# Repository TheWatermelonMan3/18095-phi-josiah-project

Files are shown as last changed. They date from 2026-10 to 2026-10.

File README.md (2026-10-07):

Review Assignment Due Date (https://classroom.github.com/a/fbvAo0RR)
# Clank
Team Member(s): Phi Nguyen, Josiah Main

- Write up a paragraph or two that describes your final hack's objective, and all its sensors and actuators.

TODO: Clank is designed to autonomously detect soda cans using a camera and computer vision model, navigate toward the detected can using two stepper-motor–driven wheels, and then “collect” it using a forklift mechanism controlled by an ultrasonic-sensor trigger, a stepper motor for lifting, and a servo for locking the can in place.

# Schematics and Block Diagrams

Here is the block diagram.

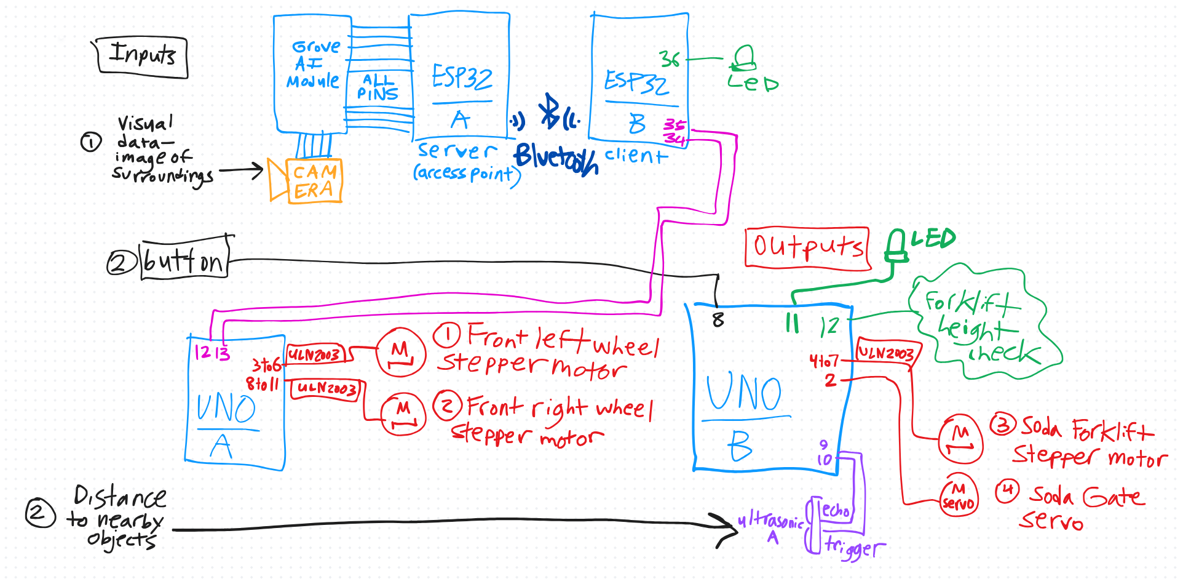
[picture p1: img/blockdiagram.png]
Block Diagram


Here is the schematic.

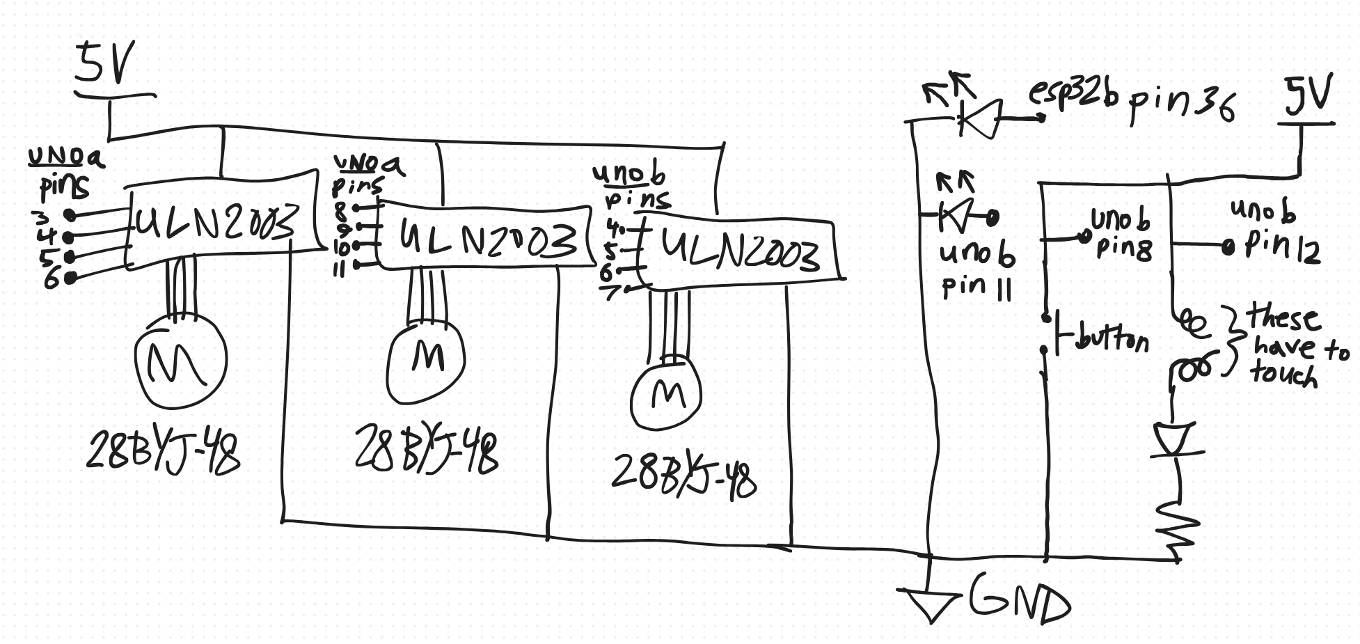
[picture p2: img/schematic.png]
Schematic


# Materials

| Item | Source (URL) |
| --- | --- |
| Grove AI Vision v2  | https://wiki.seeedstudio.com/grove_vision_ai_v2/ |
| ESP32 WROOM | https://www.alibaba.com/pla/ESP32-WiFi-BLE-ESP32-WROOM-32U-IOT-Development_1601041257369.html?product_id=1601041257369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 |
| 3x Stepper Motor | https://www.aliexpress.us/item/3256806043512709.html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 |
| Servo | https://www.aliexpress.us/item/3256807034882140.html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 |
| Ultrasonic Sensor | https://www.alibaba.com/pla/HC-SR04-Ultrasonic-Distance-Measurement-Module-HC-SR04SR04PSR04Ultrasonic_1601247237258.html?product_id=1601247237258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 |

Additionally, please upload any design files for laser-cut or 3D-printed pieces to the parts directory.

# Narrative

- Describe the process of building your final hack project.
- Did the design change as you worked on it?
- Include any problems you encountered, and how you addressed them. 
- This section should be at least ~500 words. Be reflective!

There were two separate but major goals for Clank. The first was getting the computer vision working, and the second was designing the chassis.

### Computer Vision

On the computer vision side, there was an issue getting the Grove module to work through the Seeed Studio website. Seeed Studio provides a UI that lets you upload computer vision models to their Grove AI modules very easily. I had followed the documentation correctly. I soldered the pins to the ESP32, connected the ESP32 to the Grove AI module, connected the Arduino camera with the blue strip facing up (as shown in the documentation), plugged the Grove AI module into my laptop via USB-C, and followed the instructions for uploading a model. However, after the model uploaded, the module would reset every time I tried to invoke the preview.

After what felt like hundreds of resets and boots, I started to think the module was just broken. I searched online—“Grove AI invoke not working”—and scrolled through different forums. People mentioned specific OS requirements, browser versions, etc. It wasn’t until I stumbled upon a very specific message telling someone to try flipping the camera: instead of the blue strip facing up, flip it so the blue strip faces down. I was hesitant because the documentation explicitly shows it facing up, but I didn’t have any other solutions, so I tried it. And—what do you know—it worked. I was pretty mad at the documentation. They need to fix that.

Anyway, with the Grove AI module finally able to invoke the preview, I could test different computer vision models, and we found one that fit our soda-can-identifying needs. After reading the documentation for getting the Grove module working through the Arduino IDE and implementing the code, I was able to get inference results printing in the Serial Monitor. That meant that when the model detected a soda can, its X-coordinate would be printed. This was a huge win.

The second step was turning predictions into movement. Since all the pins on the ESP32 were being used by the Grove AI module, we needed a second ESP32—with free pins—to communicate with the ESP32 on the Grove module. This was our first time setting up wireless communication between two ESP32s, so it came with a lot of challenges. The ESP32 on the Grove AI module is called the XIAO, and it does not follow the standard Bluetooth protocol used in traditional ESP32s, so we had to follow the Seeed Studio documentation for it. I was already suspicious of the documentation, but some forums had sample code, so we started with that.

The next big problem was that after we got the ESP32s talking wirelessly, it only worked when both were connected to my laptop. The moment I detached one and powered it with its own battery, it stopped working. After two days of debugging, nothing worked. I read online that a 9V battery might not provide consistent power, but I didn’t think it was a big deal because I thought the output was capped at 5V anyways. After taking the ESP32s to class and getting the TAs to help—with no success—then Tom came, looked at it for 2.6 seconds, and suggested that the battery might be low. I took out my multimeter, measured the voltage across the terminals, and found that my 9V battery was actually sitting at 6V.

After switching the battery out, the ESP32s worked completely wirelessly and independent of my laptop. The second ESP32—with free pins—was able to light up an LED when the XIAO detected a soda can.

### Robot Structure

Making the robot frame and parts was a challenge in itself. This was our first non-trivial 3D modeling and 3D printing experience. We had to learn a lot about Onshape CAD software, for example how to make construction geometries and how to assemble and mate parts to simulate how the parts would fit together. Then we also had to learn a lot about 3D slicing and printing software. Here is a summary of my challenges.

For a few days we were making the model of the wheels. We found the measurements of the 28BYJ-4 5-volt stepper motor and added a slot/hole the correct size to stick the wheel directly onto the rotating part of the motor. We didn't end up using this model - more on this later. We had to make it cleverly so that it could be printed from the bottom up with no support material. This was a challenge for designing all the models because when we think about a 3D object we usually don't have such restrictions in mind, so we might make a bridge or ceiling over something. Of course, this would be impossible to print. This went on to become a recurring theme in the modeling process.

Then we made the forklift part which would hold the soda can. We found the measurements of a standard 355mL soda can online and made a forklift with a circular rim of the same size. We added a chamfer to slope it down to the floor allowing the can to slip in smoothly. However we also needed to have a rack on the back of it so that it could be moved up and down by a pinion gear. This would be impossible to print in one piece with the forklift itself, so we cut a slot into the model and built the pinion separately so it could slide in.

Building the rack itself was also a challenge. We used an Onshape script to generate the pinion gear, and then cut a hole in it according to the measurement of the 28BYJ-4 stepper motor. The hard part was when we had to contruct the pinion ourselves with the proper angles. This was difficult due to our limited Onshape knowledge. In particular we had to learn how to make construction lines, and we weren't sure how to generate lines with a certain angle fixed between them. But the rack and pinion ended up meshing satisfactorily, which was a huge win!
We used this video to learn how to make the rack: https://www.youtube.com/watch?v=wLZq1ZXhPfE

Then we wanted to test the rack and pinion so we had to make a mate relation allowing them to move with one another. This was a steep learning curve because w didn't even know what a mate relation was. After about a day of work, we connected the rack and pinion in simulation, and the forklift was looking like it would move nicely.

We continued modeling more parts, including a chassis. The chassis had a wide rail to support the forklift while it slid up and down. We opted for having skids on the back rather than four wheels - which may have been suboptimal because dragging on the ground led to a lot of friction. We realized in the chassis we had another item we couldn't simply print from the bottom up - a place for the stepper motor to connect. We modeled a stepper motor holder piece and made three copies of it. We modeled a ceiling and a piece to slot into it which would hold the camera with four pins. Finally the models were finished and it was time to print!

We went to TechSpark to print and found that the models were too large to be contained in the Ender Creality 3 printers we were using. We redesigned many parts to slightly trim down the size. We attempted to print the parts on two printers, but on the first attempt both prints failed. We worked with TechSpark staff to identify that this was a leveling issue with the build plate. We leveled the printers properly and printed them over the weekend leading up to the final showcase. One print failed due to extruding problems, but we got the chassis, a stepper holder, skids, forklift, rack, pinion, and many other items. This was great! Some of them had tolerances a bit off and needed to be sanded down and filed to fit, particularly the skids and the forklift.

We realized the roof would take too many hours to print, but it was essentially a flat rectangular prism with holes in it. This made it easy to laser cut. We converted one of our Onshape 3D models to a .dxf file and ran it through the Epilog laser cutter. It cut perfectly on the first try and fit right on top of the chassis. We hot glued the roof to the chassis so it wouldn't slide around.

We finally got them all fitting properly, while we worked on printing the other parts that had failed to print. From this we got some wheels, stepper holders, and a camera holder. Unfortunately none of these ended up being usable - the wheels had holes too large to fit on the pegs of the stepper motors; the stepper holders were too thick, not allowing clearance for the wheels to fit onto the pegs of the stepper motors; the camera holder didn't print properly and the pins on it snapped.

We printed new, thinner, stepper holders in white, which worked great. Along with them we printed a sturdier camera mount, including having a draft angle on the pins of the camera holder so they tapered. Being thicker at the base, the pins were less likely to snap off. Now we just needed the wheels.

Making the wheels ended up being one of the most stressful parts of the process. After two failed prints that didn't work because of sloppy CAD design, we realized it was wasting lots of time and lots of filament to 3D print each time. We tried to cut wheels out of acrylic. On our first try the holes in the wheels were misaligned because we cut the wheel out of the acrylic sheet before cutting the hole into it, so the wheel fell down and moved during cutting. On my second try, the holes were aligned alright, but sadly the holes were a little too loose, making them wiggle on the stepper motors. Worse, they were slick acrylic and couldn't get enough traction to roll the robot forward. Wanting to move on to assembling the robot and coding, we opted to just add some hot glue around the wheel rims and axle holes to make the holes smaller and add traction to the rims.

In order to put the parts together we used black electrical tape. Some of the parts moved around slightly when the tape was not tight enough, but it got the job done. Finally the robot frame was completely built, just in time to put the electronics on and write the code for the final showcase!

### Motor and Power Issues

When we had added the stepper motors, we had a lot of issues powering them. The first issue was that we powered them from the Arduino Uno boards. This is not allowed because the motor driver draws far too much current to feasibly come from the Uno. So then we tried to shift to another battery supply. Eventually we connected 3 9V batteries with 5V voltage regulators in parallel on a breadboard. This allowed us to supply 3 times the current at the same voltage. Even then, the motors were not getting a lot of current, making them very, very slow. This was an issue we faced even going into the final showcase. There was also the possibility that we might have damaged certain of the components like the Uno board by attempting to run them at higher speed and lower power than was reasonable. We found that the Uno could still be used for sending and receiving high and low voltage signals, but swapped it out for a spare Uno just in case.

### Changes to Design

We removed and added some components. We decided not to use the infrared remote control to start and stop the robot, instead opting for a simple button. This was mostly due to time constraints.

We had to change the number of boards we were using to have enough pins, in particular adding another Arduino Uno board.

# System Photos

- Include photos that describe your system in the img directory.
- Include a descriptive caption for each image.

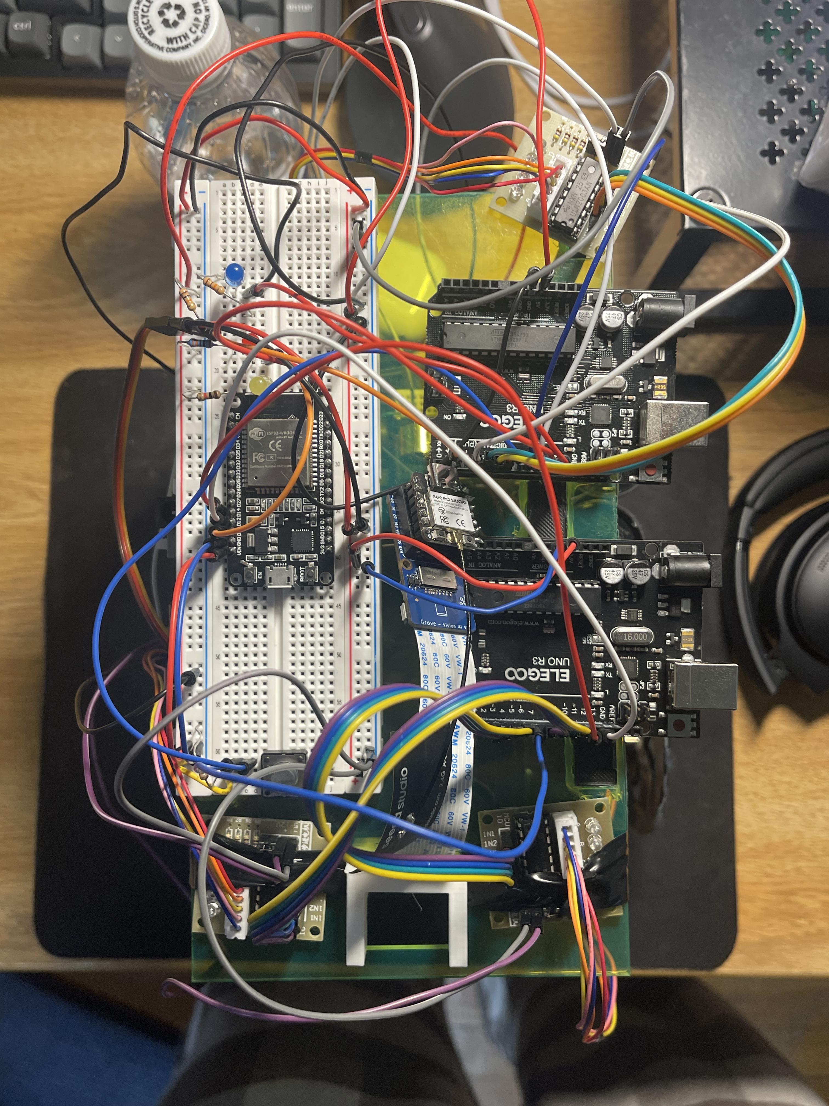
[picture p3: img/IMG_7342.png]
top view

Top view where you can see the motor controllers, breadboard, Grove module, ESP32 boards, and Arduino Uno boards

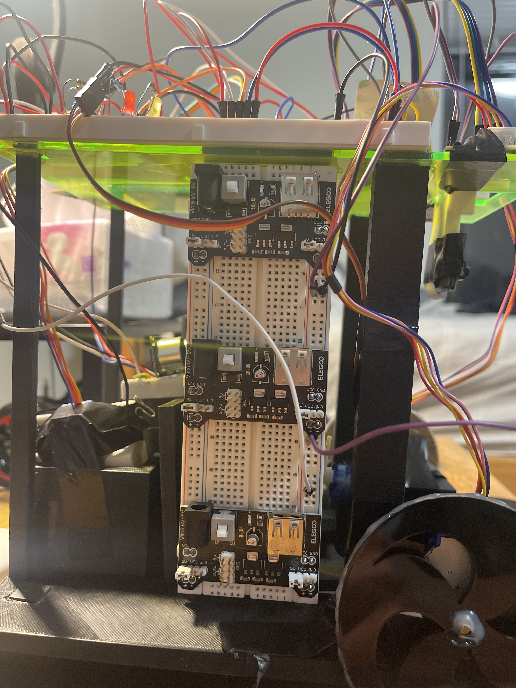
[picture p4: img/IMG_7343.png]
side view

Side view where you can see the breadboard with battery 5V regulators, ultrasonic distance sensor, stripped wire for calibrating forklift, and wheels.

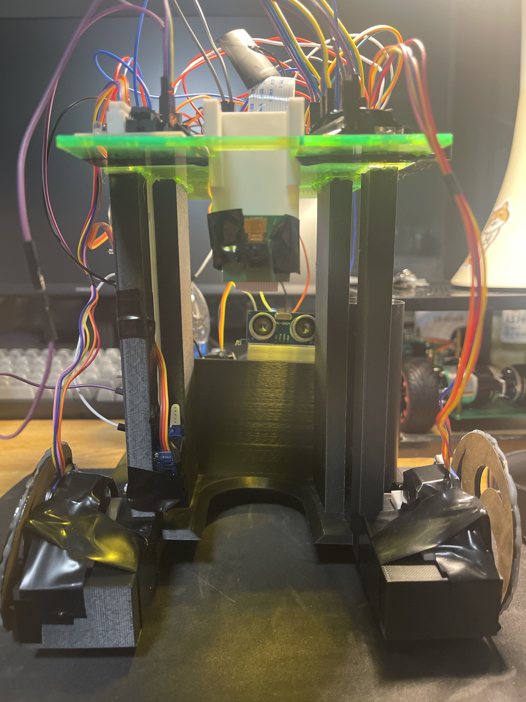
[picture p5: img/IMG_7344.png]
front view

Side view where you can see the ultrasonic distance sensor, forklift, and Raspberry Pi Camera.

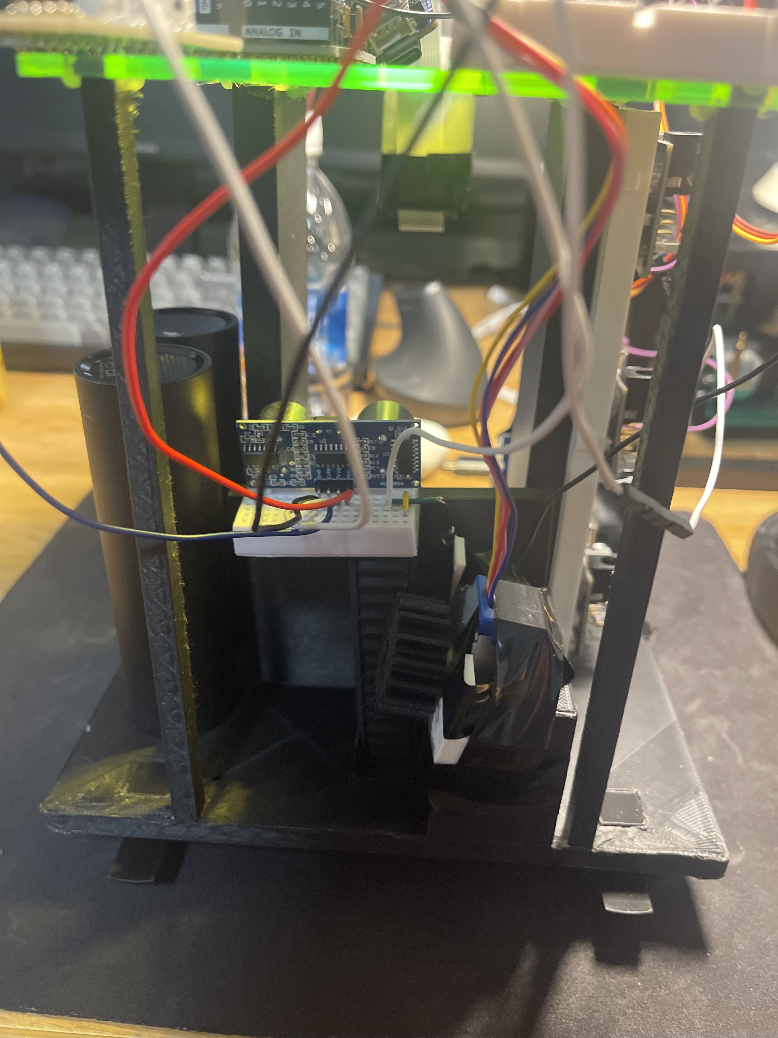
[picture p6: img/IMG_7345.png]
rear view

Rear view where you can see the battery packs, rack and pinion, and stepper for the forklift. Right now it is a little crooked.

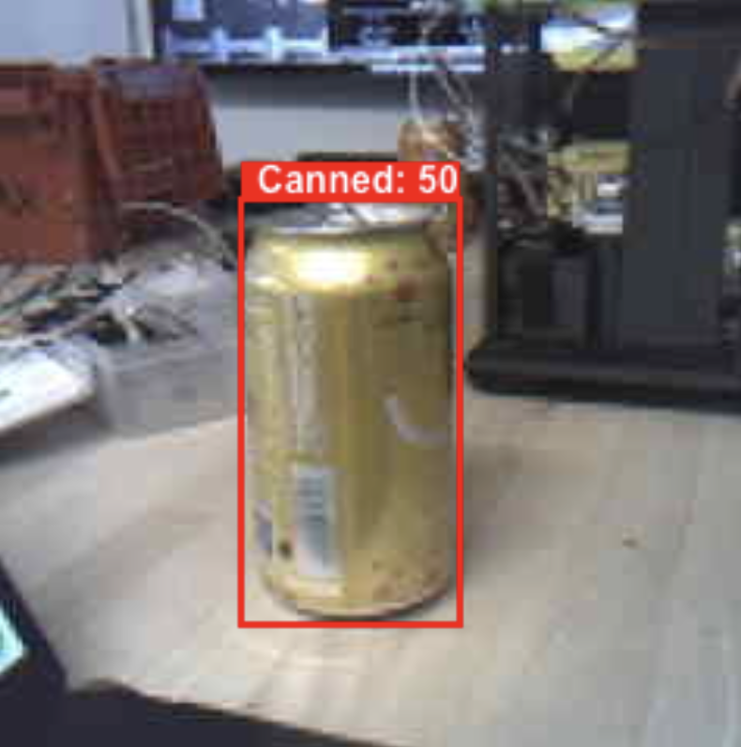
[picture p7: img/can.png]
Alt text (appears when hovering mouse over)

Grove AI module identifying a bounding box for a soda can.

# Code Description

- See the code folder.

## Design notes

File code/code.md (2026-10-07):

Description of code here! It's good to describe what each file does and any dependencies.

### infrence.ino

This file is flashed onto the XIAO ESP32 which sits on top of the Grove AI module. This code is responsible for interfacing with the Grove AI module using sample code that was refactored from the Seeed Studio website. After opening a BLE server the ESP32 will invoke the AI module and periodically call to make an infrence. If there were no soda cans in sight, a 0 will be sent to who ever is connected to the BLE server. If a soda can is found, the X coordinated will be parsed and then published to the BLE server. 

### reciever.ino

This file is flashed onto the second ESP32 that has free pins. This code is a bit more complicated because it has to deal with disconnections and dynamically trying to reconnect to the BLE server hosted by the XIAO all while interpretting the XIAO results and sending commands to through wired connections to other Arduinos that control the different actuators. The ESP32 will start by scanning for a open BLE server on the specified port, then when it connects it looks for data sent by the XIAO. After it recieves data, it will add an offset because the X coord that is recieved is actually the corner of the soda can, not the middle. With the updated X coord, there is a "deicison tree" thats very simple which tells the Arduinos what directions the stepper motors should spin in based on whether Clank needs to turn left, right, or go straight. 

### forklift.ino

This file was on the first Arduino Uno which was not connected to any other boards except for a shared ground. This code controls the forklift using a finite state machine. First the forklift is in calibration state and moves down until a stripped wire on the forklift touches another stripped wire on the frame of the robot and completes a circuit. This indicates that the forklift is at a good starting position on the floor. Then the forklift moves into detection state where it uses a distance sensor to find the distance of the nearest object. If it's closer than 3 inches, the servo is moved to close the gate (making sure the can can't fall out) and the forklift is then raised up. Then the forklift is in holding state where it waits for a button press. When that happens, the forklift drops and the servo gate opens. Then the forklift is in waiting state as it waits until the distance reading is more than 3 and less than 10 inches (removing the can).

### *missing file: wheeldriver.ino*

This file was on the second Arduino Uno which was connected to the wheel servo motor drivers. I accidentally deleted this file and it cannot be recovered. It is a simple arduino script which listens for high voltages on three different pins: left wheel pin, right wheel pin, and reverse pin. Here is how the logic of it worked:
* If the reverse pin has a high voltage, reverse both wheels for two seconds.
* Otherwise:
    * If the left wheel and right wheel pins both have high voltage, step both wheels forward little by little to drive forward.
    * If the left wheel pin has high voltage and right wheel pin has low voltage, step the left wheel forward and the right wheel backward little by little to pivot toward the right side.
    * If the right wheel pin has high voltage and left wheel pin has low voltage, step the right wheel forward and the left wheel backward little by little to pivot toward the left side. 
The rotation is achieved by doing small steps to both the left and right stepper motor in turn. I think it was about 20 steps on each one alternating rapidly between them. The stepper speed was about 8.

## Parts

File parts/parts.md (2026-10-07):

# Parts

Here are the files I used to build the robot:
 * **Soda Rover 1 of 2.stl** contains the robot frame, rear sliders, rack and pinion, camera holder (not used in final version), and stepper motor holder.
 * **Soda Rover 2 of 2.stl** contains the wheels (not used in final version) two stepper motor holders, and a roof (not used in final version).
 * **Soda Rover Final Parts.stl** contains two stepper motor holders and two wheels.
 * **sodarovermissingparts.stl** contains a better camera holder and three better stepper motor holders.
 * **SodaRoverRoof.dxf** is a laser cut for the roof of the robot.
 * **two wheel cut with holes fixed.dxf** is a laser cut for the wheels of the robot.

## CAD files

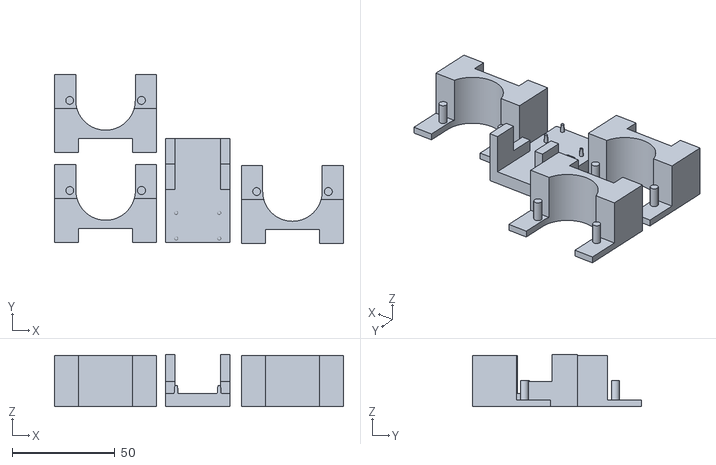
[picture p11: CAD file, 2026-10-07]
parts/sodarovermissingparts.stl
141.0 x 82.6 x 25.4

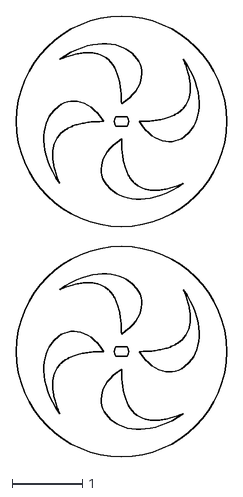
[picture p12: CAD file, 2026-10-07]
parts/two wheel cut with holes fixed.dxf
3.00 x 6.28

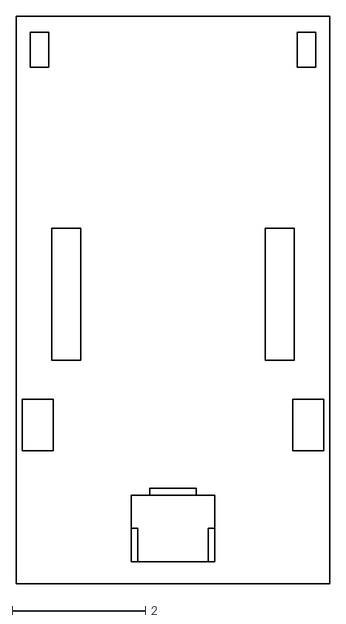
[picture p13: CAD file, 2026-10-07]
parts/SodaRoverRoof.dxf
4.70 x 8.50

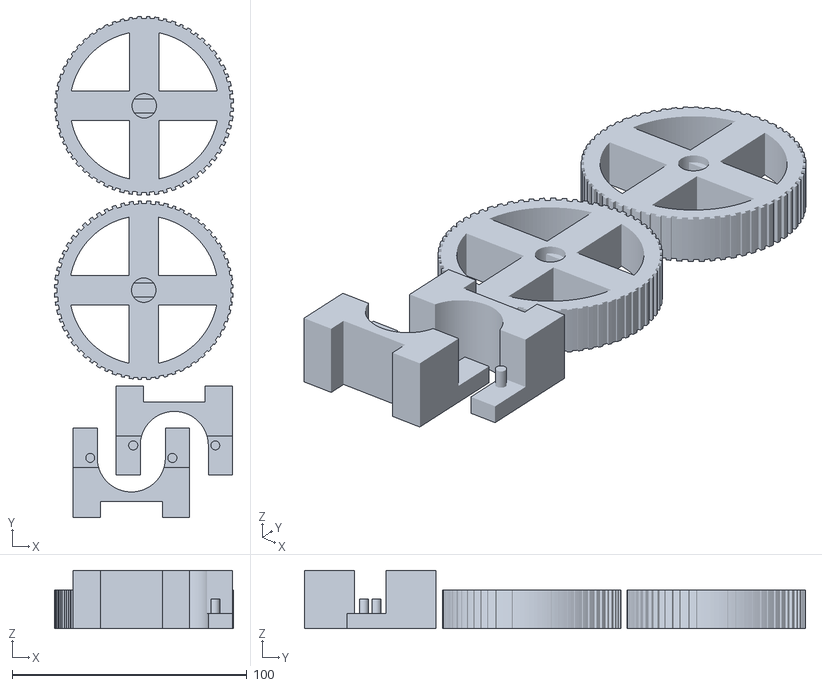
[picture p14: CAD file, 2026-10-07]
parts/Soda Rover Final Parts.stl
76.4 x 213.6 x 24.9

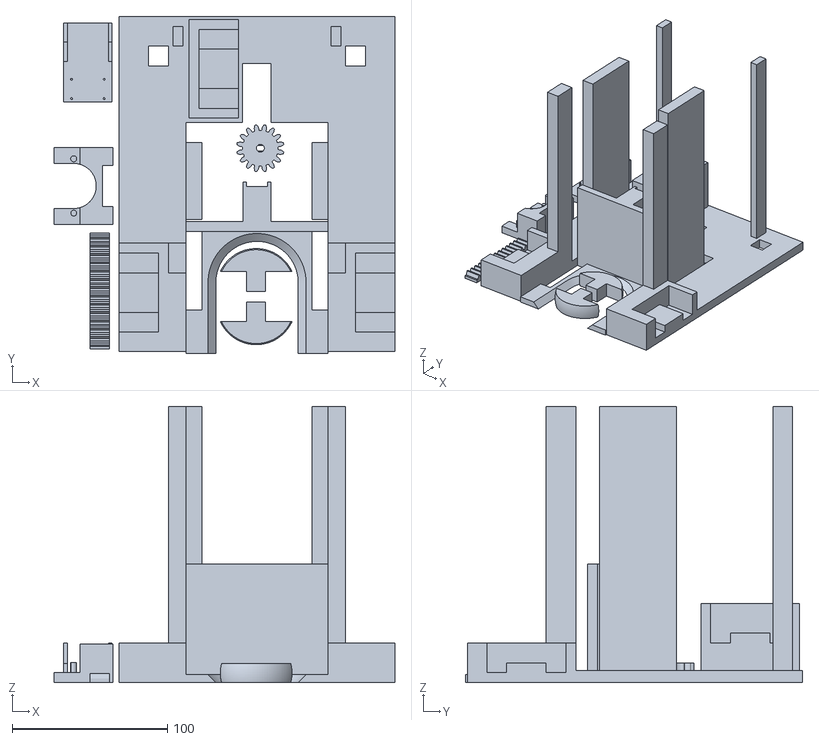
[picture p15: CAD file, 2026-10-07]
parts/Soda Rover 1 of 2.stl
219.6 x 217.1 x 177.8

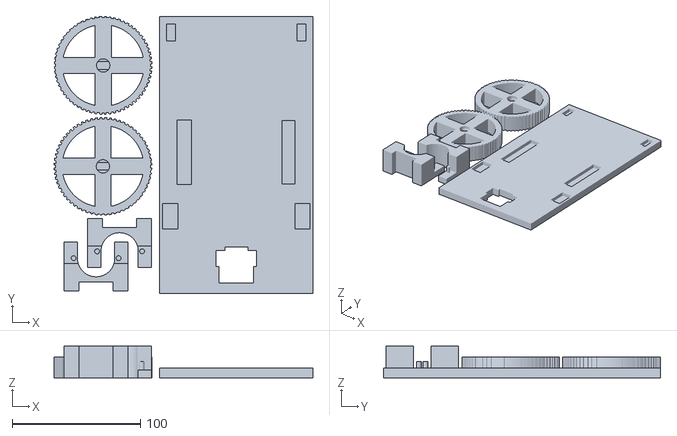
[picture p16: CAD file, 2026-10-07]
parts/Soda Rover 2 of 2.stl
201.7 x 215.9 x 24.9

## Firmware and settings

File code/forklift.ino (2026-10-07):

#include <Stepper.h>
#include <Servo.h>

const int stepsPerRevolution = 2048;

Stepper myStepper = Stepper(stepsPerRevolution, 7, 5, 6, 4);
Servo myServo;

const int trigPin = 9;  
const int echoPin = 10;
const int dropItPin = 8;
const int forkliftFloorPin = 12;
float duration, distance;

void setup() {
  // put your setup code here, to run once:
  pinMode(trigPin, OUTPUT);  
	pinMode(echoPin, INPUT);
  pinMode(forkliftFloorPin, INPUT);
  pinMode(dropItPin, INPUT);
  pinMode(11, OUTPUT);
	Serial.begin(9600);
  myServo.attach(2);
}

void loop() {

  distance = 10.0;
  myServo.write(0);

  // Calibrate Forklift
  while (digitalRead(forkliftFloorPin) == HIGH){
    myStepper.setSpeed(10);
    myStepper.step(50);
    delay(500);
  }
  while (digitalRead(forkliftFloorPin) != HIGH){
    myStepper.setSpeed(10);
    myStepper.step(-50);
    delay(500);
  }
  myStepper.step(50);

  // Wait until the can is close
  while (distance >= 2.5) {
    senseDistance();
    digitalWrite(11, HIGH);
    delay(50);
    digitalWrite(11, LOW);
    delay(50);
  }

  // Turn on indicator light
  digitalWrite(11, HIGH);

  // Let wheels drive forward into the can
  delay(2000);

  // Lock gate
  myServo.write(90);
  // Raise forklift
  myStepper.setSpeed(5);
  myStepper.step(600);

  // Wait for button press
  while (digitalRead(dropItPin) != HIGH) {
    delay(100);
  }

  // Drop that thing
  myStepper.setSpeed(10);
  myStepper.step(-600);
  myServo.write(0);

  // Wait until the can is far
  while (distance <= 2.5 || distance >= 10.0) {
    senseDistance();
    delay(100);
  }

  // Turn off indicator light
  digitalWrite(11, LOW);
}

void senseDistance() {
  // put your main code here, to run repeatedly:
  digitalWrite(trigPin, LOW);  
	delayMicroseconds(2);  
	digitalWrite(trigPin, HIGH);  
	delayMicroseconds(10);  
	digitalWrite(trigPin, LOW);
  duration = pulseIn(echoPin, HIGH);
  distance = (duration*.0343)/2;
  Serial.print("Distance: ");  
	Serial.println(distance);
}

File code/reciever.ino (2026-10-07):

#include <BLEDevice.h>
#include <BLEUtils.h>
#include <BLEClient.h>

#define SERVICE_UUID        "cafe0001-0000-0000-0000-123456789abc"
#define CHARACTERISTIC_UUID "cafe0002-0000-0000-0000-123456789abc"

#define LED_PIN 13     // Status LED output on ESP32
#define BOOT_LED 2     // Onboard LED
#define PIN12 12       // Signal output 1
#define PIN14 14      // Signal output 2

class MyClientCallback : public BLEClientCallbacks {
  void onConnect(BLEClient* pClient)  { Serial.println("Connected to server"); }
  void onDisconnect(BLEClient* pClient){ Serial.println("Disconnected from server"); }
};

BLEClient* pClient = nullptr;
BLERemoteCharacteristic* pCharacteristic = nullptr;
BLEAdvertisedDevice* target = nullptr;

void connectToServer() {
  if (target == nullptr) return;

  if (pClient) { delete pClient; pClient = nullptr; }

  pClient = BLEDevice::createClient();
  pClient->setClientCallbacks(new MyClientCallback());

  Serial.println("Connecting to server...");
  if (!pClient->connect(target)) {
    Serial.println("❌ Failed to connect. Retrying...");
    delay(2000);
    return;
  }

  BLERemoteService* pService = pClient->getService(SERVICE_UUID);
  if (!pService) {
    Serial.println("❌ Service not found!");
    pClient->disconnect();
    return;
  }

  pCharacteristic = pService->getCharacteristic(CHARACTERISTIC_UUID);
  if (!pCharacteristic) {
    Serial.println("❌ Characteristic not found!");
    pClient->disconnect();
    return;
  }

  Serial.println("✅ Connected and ready!");
  delay(100);
}

void setup() {
  // Boot pulse
  pinMode(BOOT_LED, OUTPUT);
  digitalWrite(BOOT_LED, HIGH);
  delay(300);
  digitalWrite(BOOT_LED, LOW);

  Serial.begin(115200);
  Serial.println("Starting BLE Client...");

  // Setup output pins
  pinMode(LED_PIN, OUTPUT);
  pinMode(PIN12, OUTPUT);
  pinMode(PIN14, OUTPUT);

  digitalWrite(LED_PIN, LOW);
  digitalWrite(PIN12, LOW);
  digitalWrite(PIN14, LOW);

  BLEDevice::init("ESP32_WROOM_Client");
  delay(500);

  BLEScan* pScan = BLEDevice::getScan();
  pScan->setActiveScan(true);

  while (target == nullptr) {
    Serial.println("🔍 Scanning for sender...");
    BLEScanResults results = *pScan->start(5, false);

    for (int i = 0; i < results.getCount(); i++) {
      BLEAdvertisedDevice d = results.getDevice(i);
      if (d.getName() == "XIAO_ESP32C3_Sender") {
        target = new BLEAdvertisedDevice(d);
        Serial.println("✅ Found sender!");
        break;
      }
    }

    if (!target) {
      Serial.println("Sender not found. Retrying...");
      delay(2000);
    }
  }

  connectToServer();
}

void loop() {
  if (!pClient || !pClient->isConnected()) {
    Serial.println("Reconnecting...");
    connectToServer();
    delay(2000);
    return;
  }

  if (!pCharacteristic) {
    Serial.println("⚠️ No characteristic");
    delay(500);
    return;
  }

  // Read BLE data
  String value = pCharacteristic->readValue();
  Serial.print("📩 Received: ");
  Serial.println(value);

  int x = value.toInt();
  x += 20;

  // Status LED
  digitalWrite(LED_PIN, (x > 1) ? HIGH : LOW);

  // ---- Direction Control Logic ----

  if (x < 100) {
    // Turn LEFT → activate ONLY pin 12
    digitalWrite(PIN12, HIGH);
    digitalWrite(PIN14, LOW);
  }
  else if (x >= 100 && x <= 140) {
    // Go STRAIGHT → activate BOTH pins
    digitalWrite(PIN12, HIGH);
    digitalWrite(PIN14, HIGH);
  }
  else if (x > 140) {
    // Turn RIGHT → activate ONLY pin 13
    digitalWrite(PIN12, LOW);
    digitalWrite(PIN14, HIGH);
  }

  delay(250);
}
